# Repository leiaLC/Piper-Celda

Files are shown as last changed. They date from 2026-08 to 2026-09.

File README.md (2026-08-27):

# PiperCelda — celda de digitalización Omica

Simulación en Gazebo Harmonic + MoveIt 2 de una celda robótica que toma
laminillas de un escurridor y las coloca en microscopios Zaber Nucleus MSR.
El brazo es un **AgileX PiPER X** de 6 GDL con pinza paralela.

---

## Requisitos

- Ubuntu 24.04
- ROS 2 Jazzy
- Gazebo Harmonic (`gz sim` 8.x)

```bash
sudo apt install -y \
  ros-jazzy-gz-ros2-control ros-jazzy-ros-gz-sim ros-jazzy-ros-gz-bridge \
  ros-jazzy-moveit ros-jazzy-joint-state-broadcaster \
  ros-jazzy-joint-trajectory-controller ros-jazzy-position-controllers \
  ros-jazzy-xacro ros-jazzy-controller-manager
```

Solo para regenerar geometría (no hace falta para correr la simulación):

```bash
pip install --break-system-packages trimesh shapely rtree mapbox-earcut \
  fast-simplification coacd scipy numpy
```

---

## Arrancar

Dos terminales.

### Terminal 1 — Gazebo

```bash
cd ~/Omica/PiperCelda
source /opt/ros/jazzy/setup.bash
colcon build --symlink-install
source install/setup.bash
export __NV_PRIME_RENDER_OFFLOAD=1 __GLX_VENDOR_LIBRARY_NAME=nvidia
ros2 launch piper_celda_gazebo celda_piper.launch.py
```

Espera a que los tres controladores estén activos:

```bash
ros2 control list_controllers
# joint_state_broadcaster   ... active
# brazo_controller          ... active
# pinza_controller          ... active
```

### Terminal 2 — MoveIt + RViz

```bash
cd ~/Omica/PiperCelda
source /opt/ros/jazzy/setup.bash
source install/setup.bash
ros2 launch piper_celda_moveit moveit.launch.py
```

RViz arranca ya configurado y publica la escena de la celda a los 10 s.
Espera a ver `You can start planning now!`.

Para planificar: panel **MotionPlanning**, pestaña *Planning*, grupo `brazo`,
elige un *Goal State* o arrastra el marcador del TCP, **Plan**, **Execute**.

### Argumentos útiles

| Launch | Argumento | Por defecto | Para qué |
|---|---|---|---|
| `celda_piper` | `gui` | `true` | `false` = solo servidor |
| `celda_piper` | `pausado` | `false` | arrancar en pausa |
| `celda_piper` | `x` `y` `z` `yaw` | de `pose_brazo.yaml` | mover la base del brazo |
| `moveit` | `rviz` | `true` | `false` = solo `move_group` |
| `moveit` | `escena` | `true` | publicar la geometría de la celda |
| `moveit` | `seguir` | `true` | seguir en vivo lo que muevas en Gazebo |
| `moveit` | `retardo` | `10.0` | espera antes de publicar la escena |

---

## Estructura

```
~/Omica/PiperCelda/src/
├── piper_celda_description/     brazo: URDF, mallas, controladores
│   ├── config/pose_brazo.yaml   POSE DE LA BASE (fuente única)
│   ├── config/piper_controllers.yaml
│   ├── meshes/dae/              visual (9 mallas)
│   ├── meshes/collision/        cascos convexos
│   ├── meshes/extra/            gripper_base y J8 corregida
│   └── urdf/piper_x.urdf.xacro
├── piper_celda_gazebo/          mundo y modelos de la celda
│   ├── worlds/celda_piper.sdf
│   ├── models/{mesa,microscopio_msr,escurridor_60,laminilla}
│   └── launch/celda_piper.launch.py
└── piper_celda_moveit/          planificación
    ├── config/piper_x.srdf      grupos y matriz de colisiones
    ├── config/moveit.rviz
    ├── launch/moveit.launch.py
    └── scripts/
        ├── publicar_escena_celda.py
        └── manipular_laminilla.py
```

---

## La laminilla

MoveIt trata la laminilla como obstáculo rígido, así que rechaza cualquier
trayectoria que la roce — incluido el propio agarre. Dos mecanismos, en
momentos distintos:

```bash
# ANTES de planificar la aproximación: los dedos pueden tocarla
ros2 run piper_celda_moveit manipular_laminilla.py permitir

# AL CERRAR la pinza: pasa a ser parte del robot y viaja con él
ros2 run piper_celda_moveit manipular_laminilla.py adjuntar

# AL SOLTARLA
ros2 run piper_celda_moveit manipular_laminilla.py soltar

# Ver en qué estado está todo
ros2 run piper_celda_moveit manipular_laminilla.py estado
```

Con `--objeto laminilla_02 --link Link7` para otras laminillas o links.

---

## Cambiar la pose del brazo

**Solo** en `src/piper_celda_description/config/pose_brazo.yaml`. Ese archivo
lo leen los dos launch. Si pones la pose en cualquier otro sitio, Gazebo y
MoveIt acabarán discrepando y el fallo es silencioso: no hay error, solo
planes que no corresponden a la simulación.

---

## Mover objetos de la celda

Arrastra los modelos en la GUI de Gazebo: la escena de MoveIt se actualiza
sola en menos de un segundo (`seguir:=true`). Dos límites:

- Solo sigue **poses**. Si añades o borras un modelo, reinicia el nodo.
- Los cambios **no** se guardan. Cuando te convenza la disposición:
  *File → Save World As* sobre `src/piper_celda_gazebo/worlds/celda_piper.sdf`.

---

## Regenerar geometría

Solo si cambia el CAD de origen.

```bash
# Reexportar el microscopio desde FreeCAD (workbench Mesh Design,
# Meshes -> Create mesh from shape, desviación 0.1 mm), luego:
python3 herramientas/10_orientar_microscopio.py ~/Downloads/model.stl

# Colisiones por descomposición convexa (~16 L, sigue la forma real)
python3 herramientas/12_colision_convexa.py --piezas 48

# Alternativa por cajas (~25 L, más rápida de evaluar)
python3 herramientas/11_regenerar_colisiones.py --cajas 16
```

Ambas tienen `--revertir`.

---

## Problemas conocidos

**Los microscopios parpadean en RViz.** Los 48 cascos convexos se solapan y
compiten por los mismos píxeles. El *Scene Alpha* está a 0.75 para
disimularlo. Es cosmético.

**`No executable found` tras extraer un tar.** Los scripts necesitan permiso
de ejecución en el fuente, porque `--symlink-install` instala enlaces:

```bash
chmod +x src/piper_celda_moveit/scripts/*.py
colcon build --symlink-install --packages-select piper_celda_moveit
```

**`ParseError: not well-formed` al publicar la escena.** Algún `model.sdf`
tiene `<`, `>`, `&` o `--` dentro de un comentario. Gazebo lo tolera (usa
TinyXML2), Python no. Para localizarlo:

```bash
for f in src/piper_celda_gazebo/models/*/model.sdf; do
  python3 -c "import xml.etree.ElementTree as E,sys;E.parse(sys.argv[1])" "$f" \
    2>/dev/null && echo "OK   $f" || echo "ROTO $f"
done
```

En los comentarios de SDF, usa `===` para separar, no guiones.

**Gazebo renderiza en la Intel en vez de la NVIDIA.** Es óptimus sin
offload; de ahí el `failed to create dri2 screen`. Las variables
`__NV_PRIME_RENDER_OFFLOAD` del arranque lo corrigen.

---

## Notas sobre el modelo del brazo

El `piper_x_description` original de AgileX (repo `piper_isaac_sim`) tiene
tres defectos que este paquete corrige:

1. **Falta el `gripper_base`.** El URDF monta los dedos directamente sobre
   `Link6`, dejando 33 mm de aire. La malla se tomó de la descripción
   canónica de AgileX, girada 90° en Z para la convención de la variante X.
2. **`Link7` con `mass=0`** e inercia nula. Gazebo lo rechaza. Se le asignó
   la masa e inercia de `Link8`, que es su espejo.
3. **`J8.dae` con dos triángulos parásitos**, uno a 240 mm del origen.

Además, las colisiones originales usaban las mismas mallas que el visual
(`J2.dae` son 100 980 triángulos). Se sustituyeron por cascos convexos:
240 765 → 7 140 triángulos. Los dedos conservan malla original, porque un
casco convexo taparía la abertura de la pinza.

**Datos verificados por cinemática directa:** alcance horizontal máximo
838 mm, y 833 mm a la altura de la base. Home (todos los joints en 0) deja
el TCP en (0.267, 0, 0.233) m respecto de `base_link` — pero esa pose está
sobre dos topes articulares (`joint2` tiene límite inferior 0, `joint3`
superior 0), así que el SRDF define `plegado` y `listo` para evitarla.

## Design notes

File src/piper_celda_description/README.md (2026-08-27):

# piper_celda_description

Descripción del brazo **AgileX PiPER X** adaptada a **Gazebo Harmonic + ROS 2 Jazzy**
para la celda de digitalización de Omica.

Origen: `github.com/agilexrobotics/piper_isaac_sim`, paquete `piper_x_description`.

## Cambios respecto al URDF original

| # | Problema en el original | Solución aquí |
|---|---|---|
| 1 | `Link7` (dedo) declarado con `mass="0.0"` y tensor de inercia todo en cero. Gazebo lo rechaza o lo vuelve inestable. | Se le asigna la masa (0.026482 kg) y la inercia de `Link8`, que es su espejo. |
| 2 | Colisiones usando las mismas mallas DAE que el visual: `J2.dae` son 100 980 triángulos. Inviable en simulación. | Cascos convexos en STL para `base_link`–`Link6`. De 240 765 a 7 140 triángulos de colisión. Los dedos `Link7`/`Link8` conservan malla original (1 838 tri) porque un casco convexo taparía la abertura de la pinza. |
| 3 | `joint7` y `joint8` como dos prismáticas independientes. La pinza real tiene un solo actuador. | `joint8` declarado `<mimic>` de `joint7` con multiplicador −1. Solo se comanda `joint7`. |
| 4 | Sin `ros2_control`, sin plugin de simulador, sin propiedades de contacto. | Bloque `ros2_control` con `gz_ros2_control/GazeboSimSystem` + plugin `gz_ros2_control-system`. Fricción alta (μ=1.6) en los dedos. |
| 5 | Sin frame de herramienta. | Link `tcp` a 170 mm de `Link6`, entre los dedos. Es el frame que planificará MoveIt. |
| 6 | Recorrido de pinza ±0.05 m (100 mm de apertura), que no corresponde al hardware. | Limitado a 0.035 m. Ajustar si mides otra cosa en el brazo real. |

## Cinemática verificada

- 6 revolutas (`joint1`–`joint6`) + 1 GDL de pinza (`joint7`, con `joint8` espejo).
- Home (todos los joints en 0): TCP en (0.267, 0, 0.233) m respecto a `base_link`.
- Alcance horizontal máximo: **838 mm**, y **833 mm** a la altura de la base.

## Uso

```bash
# Ver el URDF resultante
xacro urdf/piper_x.urdf.xacro usar_gazebo:=false > /tmp/piper.urdf
check_urdf /tmp/piper.urdf

# Sin anclaje al mundo (brazo libre)
xacro urdf/piper_x.urdf.xacro fijar_a_mundo:=false
```

### Argumentos del xacro

| Argumento | Default | Para qué |
|---|---|---|
| `prefix` | `""` | Prefijo de nombres, por si algún día hay dos brazos. |
| `fijar_a_mundo` | `true` | Añade link `world` + joint fijo a `base_link`. Necesario para que el brazo no se vuelque sobre la mesa. |
| `usar_gazebo` | `true` | Incluye `ros2_control` y el plugin. Ponlo en `false` para RViz puro o para MoveIt Setup Assistant. |
| `controllers_file` | `config/piper_controllers.yaml` | YAML que carga el plugin. |

## Controladores

- `joint_state_broadcaster`
- `brazo_controller` — `JointTrajectoryController` sobre `joint1`–`joint6`
- `pinza_controller` — `JointTrajectoryController` sobre `joint7`

## Pendientes conocidos

- Los cascos convexos de `Link2` y `Link3` engordan ligeramente los links respecto a la
  geometría real. Para el chequeo fino de holguras contra los microscopios conviene
  contrastar con el visual.
- La pinza es la de serie. Según la decisión de rediseño de mordazas (Delrin/PEEK con
  nido en V), habrá que sustituir la geometría de `Link7`/`Link8`.

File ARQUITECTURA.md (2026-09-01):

# Cómo funciona la celda, por dentro

Documento para entender qué hace cada pieza y poder modificarla. Complementa
al README, que es la guía de uso.

---

## 1. Las tres capas y por qué están separadas

Corren tres cosas distintas que se hablan por ROS 2:

```
   GAZEBO                    ros2_control                MOVEIT
   física, contactos    <->  puente al robot      <->    planificación
   render                    controladores               colisiones
```

**Gazebo** simula física: gravedad, contactos, inercias. No sabe planificar.
Solo obedece posiciones articulares y calcula qué pasa.

**ros2_control** es el puente. Dentro de Gazebo corre el plugin
`gz_ros2_control`, que expone cada articulación como una *interfaz*: una de
comando (dónde quiero que esté) y varias de estado (dónde está, a qué
velocidad, con qué esfuerzo). Encima viven los controladores, que traducen
trayectorias en comandos.

**MoveIt** planifica. Nunca toca Gazebo directamente: calcula una trayectoria
y se la entrega a un controlador. Su modelo del mundo es la *escena de
planificación*, que alguien tiene que rellenar — ese alguien es nuestro script.

La separación importa porque **cada capa puede estar bien y el conjunto mal**.
La mitad de los problemas de esta sesión fueron eso: MoveIt planificando con
el brazo en una pose y Gazebo simulándolo en otra, o dos simulaciones a la vez
y el comando yendo a la que no mirabas.

---

## 2. El recorrido de un movimiento

Cuando pides "lleva el TCP a este punto":

1. **RViz o un script** manda un *goal* a la acción `/move_action`.
2. **`move_group`** recibe la petición. Aplica adaptadores previos (¿el estado
   inicial es válido? ¿está dentro de límites?) y llama a **OMPL**.
3. **OMPL** busca un camino en el espacio de configuraciones muestreando al
   azar. Cada muestra se comprueba contra la escena de planificación con FCL.
   Si no encuentra ninguna configuración válida que alcance el objetivo, sale
   el `Unable to sample any valid states for goal tree`.
4. Encontrado el camino, un adaptador posterior le pone tiempos
   (`AddTimeOptimalParameterization`) respetando `joint_limits.yaml`.
5. `move_group` mira `moveit_controllers.yaml`, ve qué controlador maneja esas
   articulaciones, y le manda la trayectoria por `FollowJointTrajectory`.
6. **`brazo_controller`** interpola la trayectoria y escribe posiciones en las
   interfaces de comando, ciclo a ciclo.
7. **`gz_ros2_control`** aplica esas posiciones a las articulaciones de Gazebo.
8. Gazebo integra la física y publica el estado de vuelta, que sube por la
   misma cadena hasta `/joint_states`.

Si algo falla, el paso donde falla determina el síntoma. Vale la pena
memorizar tres:

- *"Unable to sample any valid states"* → paso 3. El objetivo es inalcanzable
  o está en colisión.
- *"followed 0% of requested trajectory"* → cálculo cartesiano. El punto de
  partida ya está en colisión, o el camino recto es imposible.
- *"Aborted due to path tolerance violation"* → paso 6. El controlador manda
  pero la articulación no llega.

---

## 3. Las tres piezas del brazo

### `piper_x.urdf.xacro` — la geometría y la cinemática

Un xacro es un URDF con plantillas. Describe **links** (piezas rígidas, con
masa, inercia, malla visual y malla de colisión) y **joints** (cómo se conecta
cada link con el anterior y en qué eje gira o desliza).

La cadena es `world → base_link → Link1 … Link6 → gripper_base → Link7/Link8`,
más un link `tcp` de cortesía.

Tres cosas que conviene entender:

**El link `world` y `anclaje_mundo`.** Sin ellos el brazo sería un objeto
libre. La junta fija `world → base_link` es la que lo planta sobre la mesa, y
su origen sale de `pose_brazo.yaml`. Esta junta es la razón de que Gazebo y
MoveIt coincidan: los dos leen el mismo archivo.

**Colisión distinta del visual.** El visual usa las mallas `.dae` originales
(`J2.dae` son 100 980 triángulos). La colisión usa cascos convexos en STL, con
7 140 triángulos en total. Comprobar colisiones contra 240 000 triángulos en
cada muestra de OMPL sería inviable, y la precisión no aporta nada a esta
escala. Los dedos son la excepción: conservan malla original, porque un casco
convexo taparía la abertura de la pinza.

**`gripper_base` no viene del fabricante.** El URDF de AgileX para la variante
X monta los dedos directamente sobre `Link6`, dejando 33 mm de aire. La malla
se tomó de su descripción canónica y se giró 90° en Z.

### `piper_x.gazebo.xacro` — la interfaz de control

Aquí vive el bloque `<ros2_control>`, que declara qué articulaciones se pueden
comandar y con qué interfaces. Y el `<plugin>` que mete `gz_ros2_control`
dentro de Gazebo, apuntándole al YAML de controladores.

Aquí también están las propiedades de contacto: fricción alta (μ=1.6) en los
dedos para que la laminilla no resbale, baja en el resto.

`joint8` se comanda explícitamente, en espejo de `joint7`. La pinza real tiene
un solo actuador y lo natural sería un `<mimic>`, pero en Jazzy eso dio
problemas y la solución fue mandar los dos dedos desde el controlador.

### `piper_controllers.yaml` — los controladores

Tres: `joint_state_broadcaster` (publica `/joint_states`), `brazo_controller`
(joints 1–6) y `pinza_controller` (joints 7 y 8).

Las **tolerancias** son el parámetro con más consecuencias. Son holgadas a
propósito en la pinza: al cerrar sobre la laminilla el dedo *tiene* que
quedarse corto respecto al comando, porque hay vidrio en medio. Con tolerancia
estricta, cada agarre exitoso se reportaría como fallo. El precio es que si la
pinza se atasca de verdad, el controlador no avisa.

---

## 4. Las tres piezas de MoveIt

### `piper_x.srdf` — lo que el URDF no dice

El URDF describe la máquina. El SRDF describe **cómo usarla**:

- **Grupos**: `brazo` es la cadena de `base_link` a `tcp`; `pinza` son los dos
  dedos. Planificas sobre un grupo, no sobre el robot entero.
- **Poses con nombre**: `plegado`, `listo`, `abierta`, `cerrada`. La pose de
  todo-ceros no sirve como *home* porque `joint2` tiene límite inferior 0 y
  `joint3` superior 0: con ceros el brazo queda sobre dos topes y el
  planificador rechaza ese estado inicial.
- **La matriz de colisiones**: 26 pares desactivados. Sin ella, MoveIt
  comprobaría cada par de links en cada muestra, y además rechazaría estados
  válidos — dos links contiguos siempre se tocan en la junta.

Esa matriz no está escrita a ojo. Se calculó muestreando 3 000 configuraciones
aleatorias y midiendo qué pares llegaban a tocarse: 11 adyacentes, 14 que no
se tocaron nunca, y `Link7`/`Link8`, que hay que desactivar o MoveIt se niega
a cerrar la pinza.

### `kinematics.yaml`, `joint_limits.yaml`, `ompl_planning.yaml`

El primero elige el solucionador de cinemática inversa (KDL). El segundo pone
techo a velocidades y aceleraciones — deliberadamente por debajo de lo que
declara el URDF, porque en simulación de layout interesa poder seguir el
movimiento con la vista. El tercero configura OMPL: `RRTConnect` por defecto,
que crece dos árboles desde inicio y meta hasta que se encuentran.

### `moveit_controllers.yaml`

Le dice a MoveIt qué controlador maneja qué articulaciones. Si los nombres no
coinciden con `piper_controllers.yaml`, MoveIt planifica pero *Execute* no
hace nada.

---

## 5. `publicar_escena_celda.py` — meter el mundo en MoveIt

MoveIt no sabe nada de Gazebo. Su mundo es la escena de planificación, y
arranca vacía.

Este nodo lee **el mismo `celda_piper.sdf` que carga Gazebo**, resuelve cada
`model://` contra la misma carpeta `models/`, y publica la geometría como
objetos de colisión. Esa decisión es deliberada: no hay geometría escrita a
mano en ningún sitio, así que la escena y la simulación no pueden divergir.

Lo que hace, en orden:

1. **Parsea el SDF** con `ElementTree`. Aquí apareció un problema curioso:
   Gazebo usa TinyXML2, que tolera `<`, `>` y `--` dentro de comentarios;
   Python sigue el estándar y los rechaza. Mismo archivo, dos lectores con
   criterios distintos.
2. **Compone poses en tres niveles**: la del `<include>` en el mundo, la del
   `<model>` dentro de su archivo, y la de cada `<collision>` dentro del link.
   Se multiplican matrices de rotación y se suman traslaciones.
3. **Lee las mallas**. Lleva un lector de STL binario en Python puro para no
   depender de `trimesh` en tiempo de ejecución.
4. **Publica** por el servicio `apply_planning_scene`.

Con `seguir:=true` no termina: se suscribe a las poses que Gazebo publica
—puenteadas a `/poses_gazebo`— y reenvía cualquier modelo que muevas en la
GUI. Guarda la geometría **en el marco de cada modelo** y solo recompone la
pose cuando cambia; releer las 48 mallas del microscopio a 2 Hz sería
inviable. Refresca cada 0.5 s y solo si el modelo se movió más de 1 mm.

Solo sigue poses. Si añades o borras un modelo en Gazebo, hay que reiniciarlo.

---

## 6. `agarrar_laminilla.py` — la secuencia

### La geometría, primero

La laminilla mide 76 × 26 × 1 mm y está de canto en el escurridor. Su espesor
va en X (dirección de las ranuras), su ancho en Y, su alto en Z. Centro en
z = 0.798, borde superior en 0.836.

El punto de agarre está 20 mm por debajo del borde: **z = 0.816**. El TCP está
en la punta de los dedos, así que poner el TCP ahí hace que la zona de contacto
de las mordazas cubra exactamente esos 20 mm superiores.

**La orientación** determina dónde apoya la mordaza:

| | cierra sobre | apoyo de la mordaza |
|---|---|---|
| `cantos` | 26 mm de ancho | 1 mm de canto |
| `caras` | 1 mm de espesor | 26 mm de cara |

En las dos, el eje Z del TCP mira hacia −Z del mundo. Lo que cambia es el eje
X, que es por donde cierran los dedos. Están precalculadas como cuaterniones
en `ORIENTACIONES`.

La abertura se deduce de ahí: cada dedo se separa `joint7` del centro, así que
la abertura total es el doble. Por eso no puede haber un valor único por
defecto — 26 mm y 1 mm piden aperturas muy distintas.

### Los siete pasos

**1. Abrir la pinza.** Antes de acercarse, no después. Con una espera de un
segundo tras confirmar el movimiento: la acción reporta éxito cuando el
controlador alcanza el objetivo, pero los dedos siguen asentándose, y arrancar
el descenso con la pinza todavía abriendo empuja la laminilla.

**2. Permitir el contacto.** Se marca en la matriz de colisiones que los links
de la pinza pueden tocar la laminilla. Sin esto no hay plan posible: agarrar
*es* tocar. También se permite el contacto laminilla–escurridor, y eso no es
una concesión: la laminilla **arranca metida en la ranura**, así que en cuanto
se adjunta al robot esa interpenetración cuenta como colisión robot–mundo y
ninguna trayectoria de salida sería válida.

**3. Ir al preagarre**, 100 mm por encima. Este tramo sí es un plan articular
normal: no importa por dónde pase mientras evite obstáculos.

**4. Descenso, en dos tramos.** Libre de colisiones hasta 35 mm del agarre; los
últimos 35 mm sin comprobar colisiones. Esos milímetros son contacto por
definición y exigir ausencia de colisión ahí es contradictorio — el
planificador se planta justo al llegar al borde superior de la laminilla. El
tramo liberado es corto, estrictamente vertical, y parte de un punto que sí se
verificó. Lo único que puede tocar es la laminilla que vas a agarrar.

Los dos tramos son **cartesianos**, no articulares. Un plan articular solo
garantiza que inicio y fin están libres; por el camino el TCP puede describir
un arco, y con las ranuras vecinas a 8 mm un arco las barre.

**5. Cerrar la pinza.**

**6. Adjuntar.** La laminilla pasa del mundo a la lista de cuerpos adjuntos del
robot. Desde ahí MoveIt la mueve con el brazo y comprueba **sus** colisiones
contra la celda — importante, porque 76 mm de vidrio sobresaliendo de la pinza
cambian el volumen que hay que hacer pasar entre los microscopios.

Dos trampas aquí, ambas encontradas a golpes:

- MoveIt calcula la posición del objeto *relativa al link* usando el estado del
  robot en ese instante. Si se adjunta con el brazo en casa, la laminilla queda
  enganchada con el desfase equivocado. Por eso el script declara
  explícitamente en qué configuración está el robot.
- No hay que mandar un `REMOVE` del objeto en el mundo. Adjuntar por id ya lo
  saca. Si se manda, MoveIt procesa el borrado primero y luego no encuentra qué
  adjuntar: queda un cuerpo vacío en la pinza.

**7. Retirada**, también en dos tramos, en espejo del descenso.

### Modo seco contra ejecución real

Con `--solo-planificar` el robot no se mueve, así que cada tramo debe partir
del final planificado del anterior — si no, el segundo tramo cartesiano se
calcula desde donde está el brazo de verdad y devuelve 0 %.

En ejecución real ocurre lo contrario: cada tramo parte del estado **medido**.
Si el controlador se queda corto por unos milímetros, el siguiente tramo lo
tiene en cuenta en vez de arrastrar el error.

El modo seco deja la laminilla adjunta en la escena. Para devolverla a su
sitio, vuelve a correr `publicar_escena_celda.py`.

---

## 7. Qué tocar para cambiar cada cosa

| Quiero… | Toco |
|---|---|
| mover la base del brazo | `pose_brazo.yaml`, y **solo** ahí |
| cambiar dónde agarra | `--bajo-borde`, o el cálculo de `z_agarre` |
| agarre por cantos | `--orientacion cantos` |
| más o menos apriete | `--apriete`, `--holgura` |
| que vaya más lento | `--velocidad 0.05` |
| brazo más rápido en general | `joint_limits.yaml` |
| que deje de chocar con algo | la matriz del `piper_x.srdf` |
| añadir un obstáculo | el `celda_piper.sdf`; la escena lo recoge sola |
| otro planificador | `ompl_planning.yaml` |
| colisiones del microscopio | `herramientas/12_colision_convexa.py` |

---

## 8. Lo que esta simulación no te dice

**El agarre físico.** MoveIt lleva la laminilla adjunta cinemáticamente,
pegada a `Link7`, pase lo que pase. Gazebo simula contacto de verdad. Los dos
pueden discrepar, y de hecho discrepan: una laminilla de 5 g y 1 mm sujeta por
una pinza controlada en posición tiende a salir disparada por el error de
penetración. Que RViz muestre el agarre perfecto no significa que el agarre
real vaya a funcionar.

**Las mordazas.** El agarre por caras que usa el script por defecto **no cabe
con el escurridor lleno**: las ranuras están a 8 mm y cada mordaza tendría que
medir menos de 3 mm. Sirve para validar cinemática y secuencia; para operación
real dependen del rediseño de mordazas.

**La vibración.** Nada en esta simulación modela lo que le pasa a la óptica de
un microscopio cuando un brazo se mueve a su lado.

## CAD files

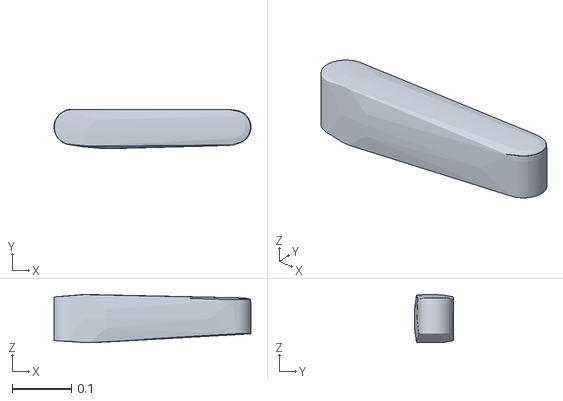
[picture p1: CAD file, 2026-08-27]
src/piper_celda_description/meshes/collision/J3_col.stl
0.331 x 0.0664 x 0.0807

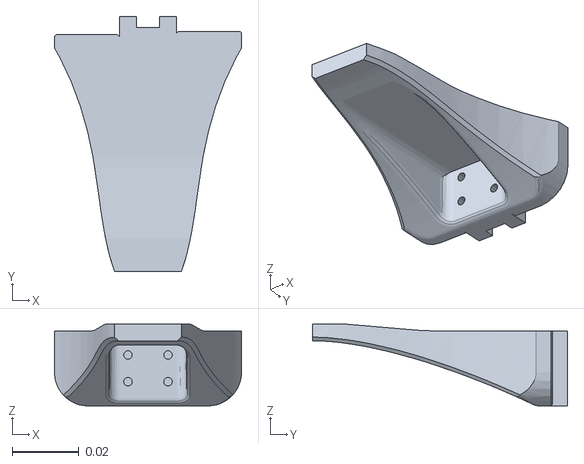
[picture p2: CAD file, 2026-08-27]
src/piper_celda_description/meshes/extra/J8_limpio.stl
0.056 x 0.0765 x 0.0245

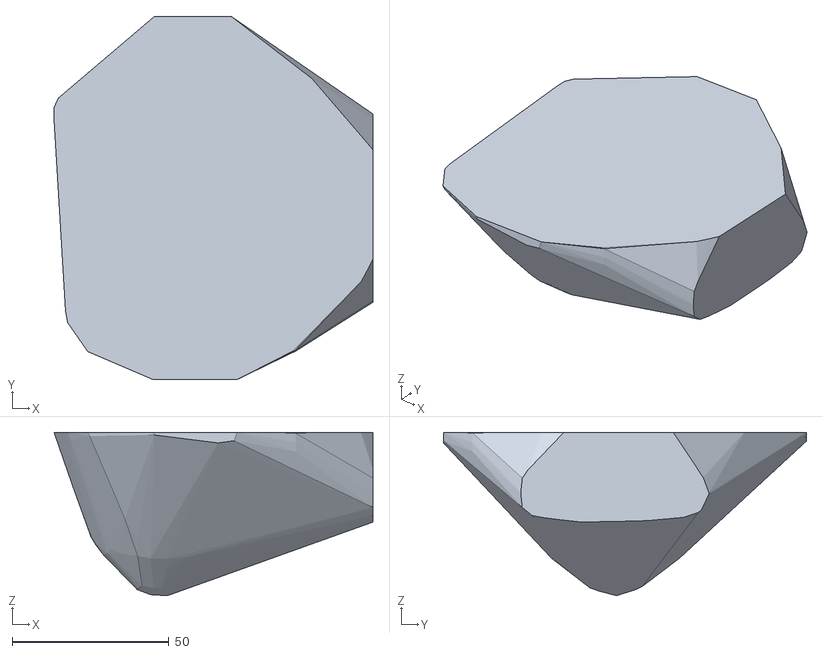
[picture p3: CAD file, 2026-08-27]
src/piper_celda_gazebo/models/microscopio_msr/meshes/collision/col_43.stl
101.8 x 115.9 x 52.1

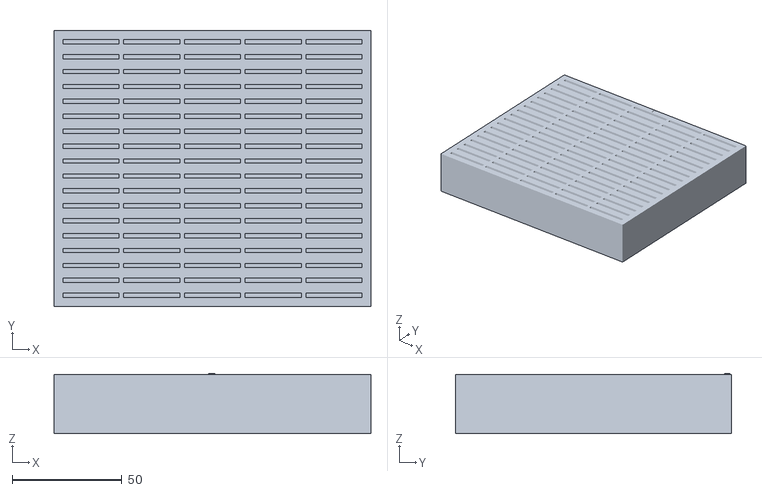
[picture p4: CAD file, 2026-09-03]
src/piper_celda_gazebo/models/rack_laminillas/meshes/rack_laminillas.stl
144.5 x 125.6 x 27.5

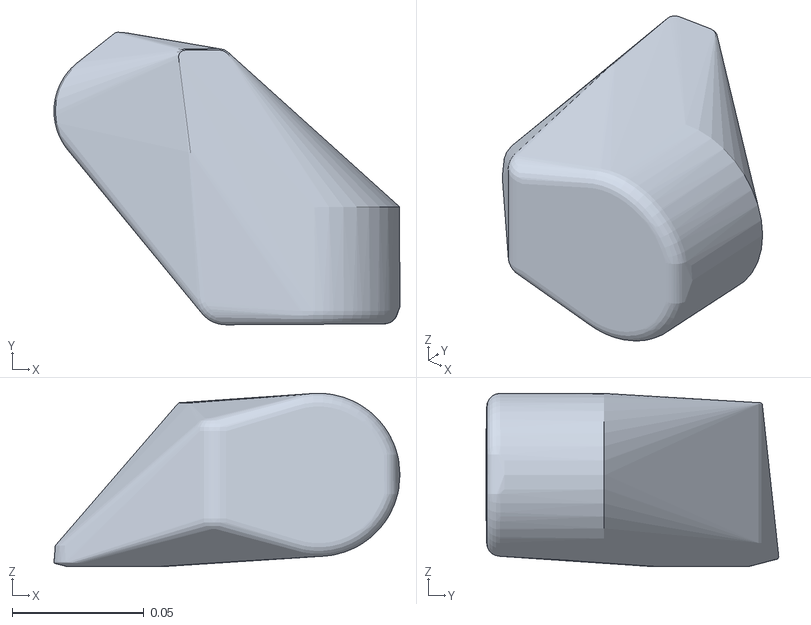
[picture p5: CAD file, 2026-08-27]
src/piper_celda_description/meshes/collision/J4_col.stl
0.132 x 0.111 x 0.0659

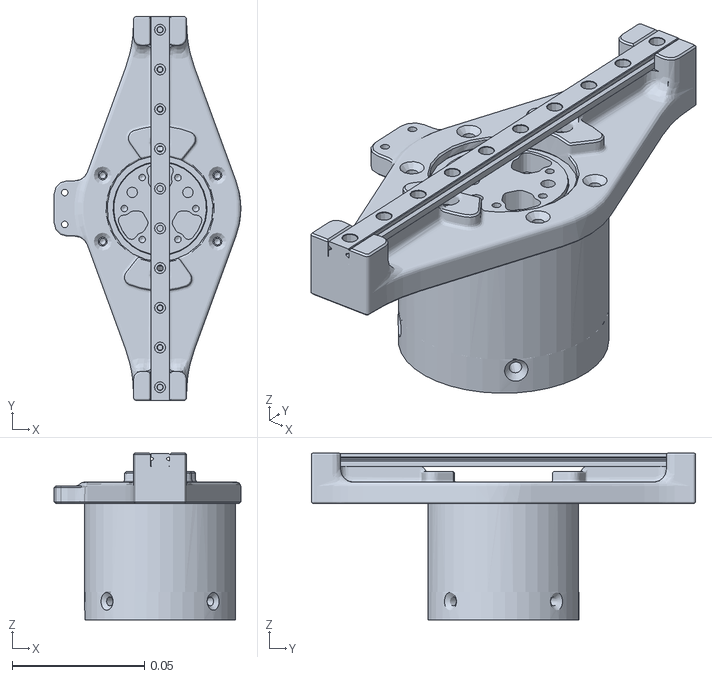
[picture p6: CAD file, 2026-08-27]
src/piper_celda_description/meshes/extra/gripper_base.stl
0.0705 x 0.145 x 0.063

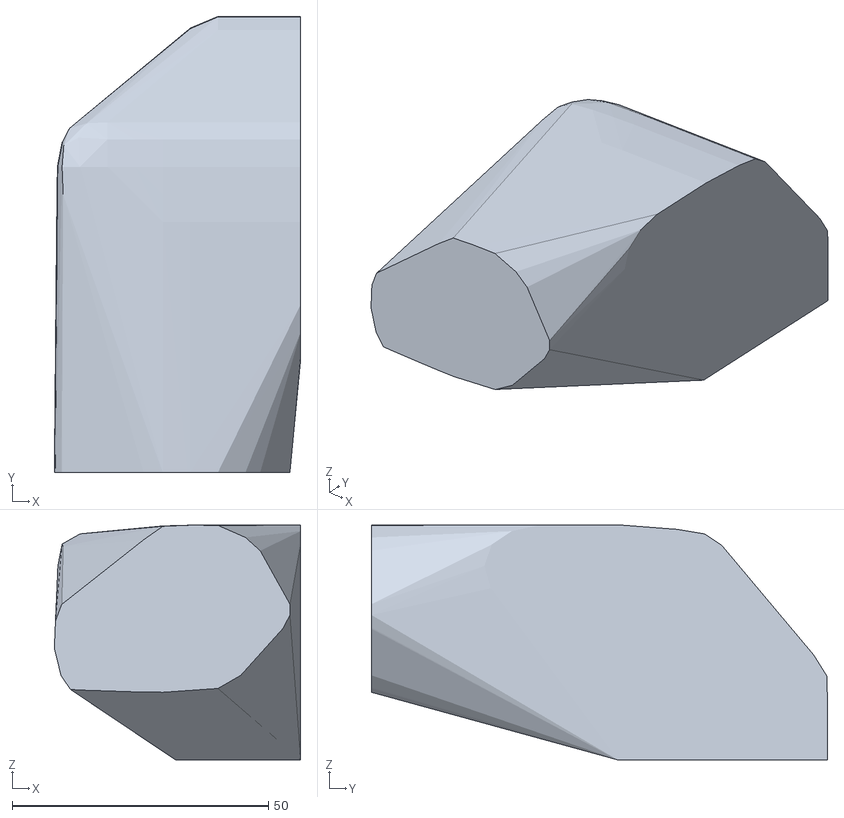
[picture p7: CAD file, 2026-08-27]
src/piper_celda_gazebo/models/microscopio_msr/meshes/collision/col_38.stl
48.1 x 89.0 x 45.8

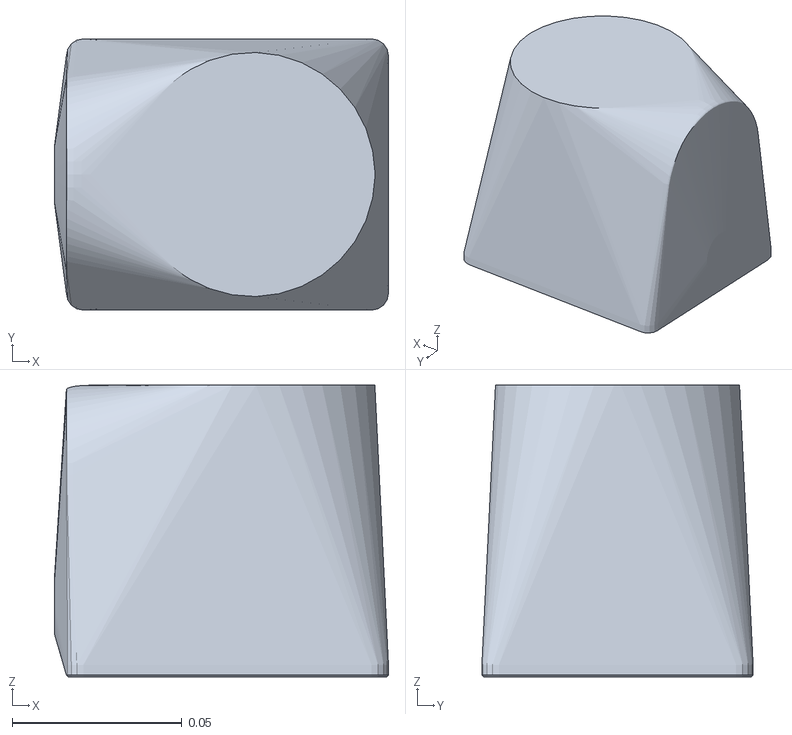
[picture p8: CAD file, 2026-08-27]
src/piper_celda_description/meshes/collision/base_Link_col.stl
0.0985 x 0.08 x 0.086

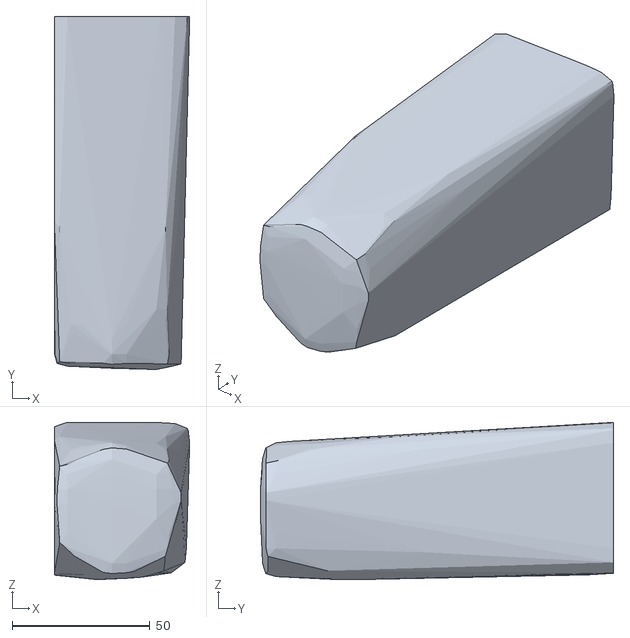
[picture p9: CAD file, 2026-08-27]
src/piper_celda_gazebo/models/microscopio_msr/meshes/collision/col_07.stl
49.1 x 127.9 x 57.0

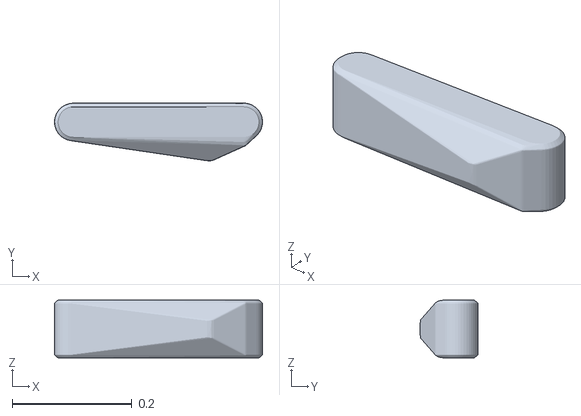
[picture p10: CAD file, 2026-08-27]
src/piper_celda_description/meshes/collision/J2_col.stl
0.348 x 0.0965 x 0.097

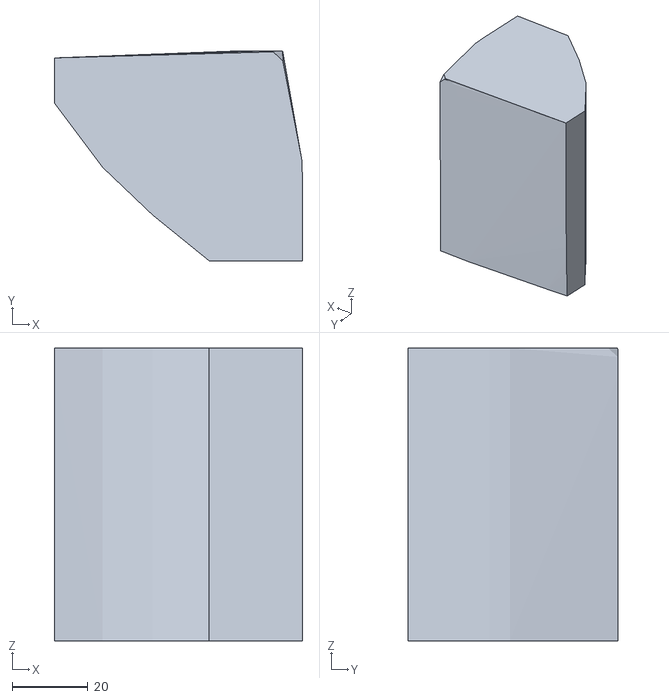
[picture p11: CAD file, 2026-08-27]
src/piper_celda_gazebo/models/microscopio_msr/meshes/collision/col_15.stl
65.7 x 55.5 x 77.6

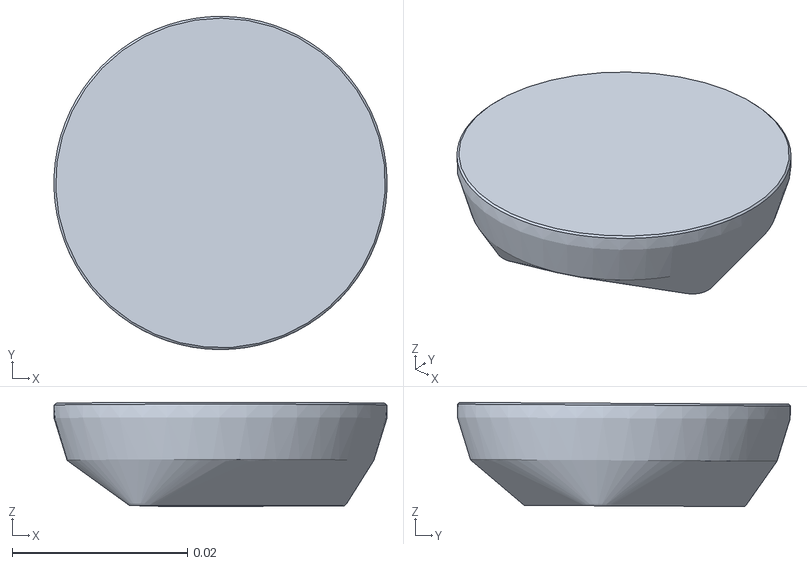
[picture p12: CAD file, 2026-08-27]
src/piper_celda_description/meshes/collision/J6_col.stl
0.038 x 0.038 x 0.0119

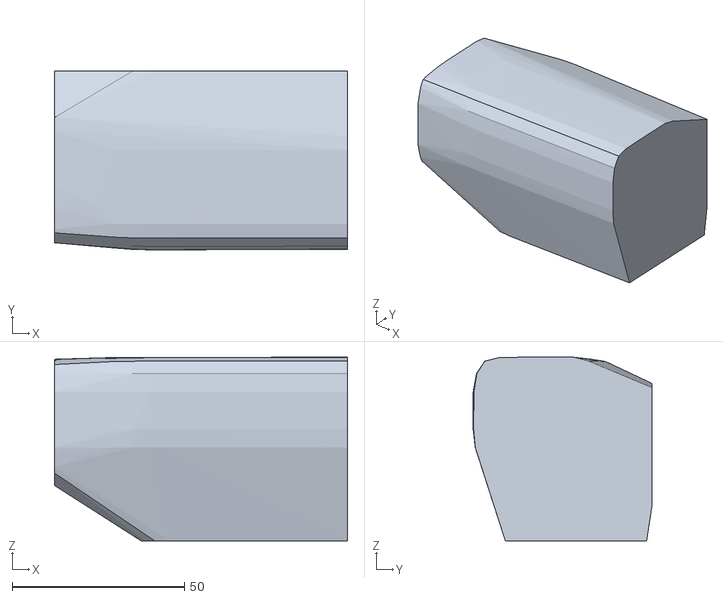
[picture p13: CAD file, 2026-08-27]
src/piper_celda_gazebo/models/microscopio_msr/meshes/collision/col_33.stl
85.2 x 52.0 x 53.4

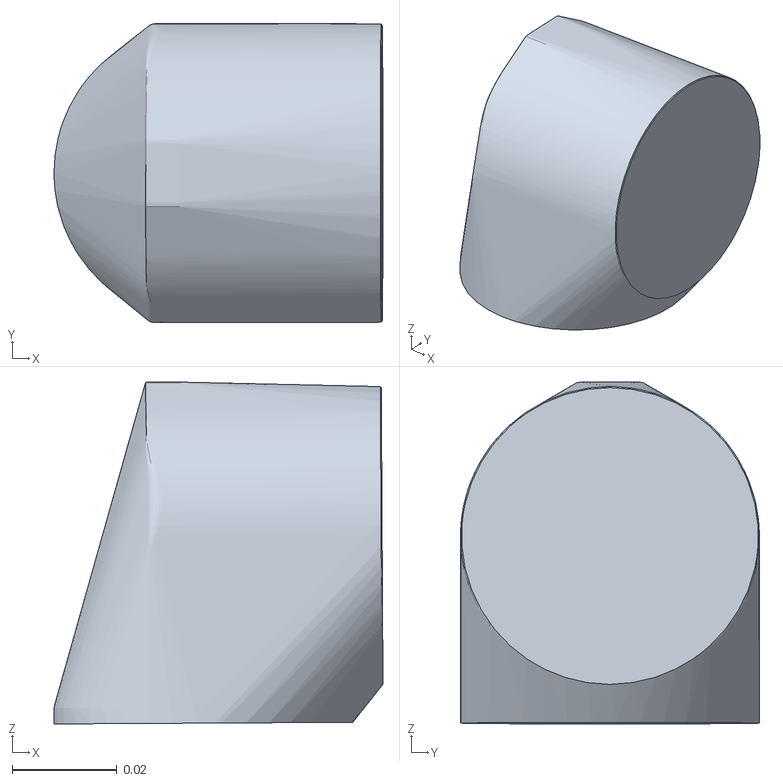
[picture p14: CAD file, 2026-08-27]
src/piper_celda_description/meshes/collision/J5_col.stl
0.0628 x 0.057 x 0.0652

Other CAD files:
src/piper_celda_gazebo/models/microscopio_msr/meshes/collision/col_03.stl
src/piper_celda_description/meshes/collision/gripper_base_col.stl
src/piper_celda_gazebo/models/microscopio_msr/meshes/collision/col_10.stl
src/piper_celda_description/meshes/collision/J1_col.stl
src/piper_celda_gazebo/models/microscopio_msr/meshes/collision/col_00.stl
src/piper_celda_gazebo/models/microscopio_msr/meshes/collision/col_01.stl
src/piper_celda_gazebo/models/microscopio_msr/meshes/collision/col_02.stl
src/piper_celda_gazebo/models/microscopio_msr/meshes/collision/col_04.stl
src/piper_celda_gazebo/models/microscopio_msr/meshes/collision/col_05.stl
src/piper_celda_gazebo/models/microscopio_msr/meshes/collision/col_06.stl
src/piper_celda_gazebo/models/microscopio_msr/meshes/collision/col_08.stl
src/piper_celda_gazebo/models/microscopio_msr/meshes/collision/col_09.stl
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

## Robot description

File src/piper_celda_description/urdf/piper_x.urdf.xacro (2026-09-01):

<?xml version="1.0"?>
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
<robot xmlns:xacro="http://www.ros.org/wiki/xacro" name="piper_x">

  <xacro:arg name="prefix" default=""/>
  <xacro:arg name="fijar_a_mundo" default="true"/>

  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
  <xacro:arg name="base_x" default="0.0"/>
  <xacro:arg name="base_y" default="0.14"/>
  <xacro:arg name="base_z" default="0.754"/>
  <xacro:arg name="base_yaw" default="1.5708"/>
  <xacro:arg name="usar_gazebo" default="true"/>
  <xacro:arg name="controllers_file" default="$(find piper_celda_description)/config/piper_controllers.yaml"/>

  <xacro:property name="P" value="$(arg prefix)"/>
  <xacro:property name="mesh" value="package://piper_celda_description/meshes"/>

  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
  <xacro:macro name="piper_link" params="name visual_mesh col_mesh mass ixx ixy ixz iyy iyz izz cx cy cz material:=piper_gris">
    <link name="${P}${name}">
      <inertial>
        <origin xyz="${cx} ${cy} ${cz}" rpy="0 0 0"/>
        <mass value="${mass}"/>
        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
      </inertial>
      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
    </link>
  </xacro:macro>

  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
  <xacro:piper_link name="base_link" visual_mesh="base_Link.dae" col_mesh="collision/base_Link_col.stl" mass="0.47421" cx="-0.0085443" cy="4.8839E-05" cz="0.044762" ixx="0.00044509" ixy="5.5896E-07" ixz="1.9736E-05" iyy="0.00049109" iyz="7.1578E-07" izz="0.00055319"/>

  <xacro:piper_link name="Link1" visual_mesh="J1.dae" col_mesh="collision/J1_col.stl" mass="0.16975" cx="0.0011378" cy="-0.0021698" cz="-0.014112" ixx="6.466E-05" ixy="7.2374E-07" ixz="5.1556E-08" iyy="8.8951E-05" iyz="1.0827E-07" izz="8.3142E-05"/>

  <xacro:piper_link name="Link2" visual_mesh="J2.dae" col_mesh="collision/J2_col.stl" mass="0.37783" cx="0.21036" cy="-0.01651" cz="0.0015283" ixx="0.00022199" ixy="3.2631E-05" ixz="-6.2643E-06" iyy="0.0019854" iyz="-3.0109E-06" izz="0.0020664"/>

  <xacro:piper_link name="Link3" visual_mesh="J3.dae" col_mesh="collision/J3_col.stl" mass="0.27675" cx="0.13372" cy="0.0056503" cz="-0.0017736" ixx="6.5229E-05" ixy="-1.7096E-05" ixz="1.6598E-06" iyy="0.00069125" iyz="4.6595E-07" izz="0.00071096"/>

  <xacro:piper_link name="Link4" visual_mesh="J4.dae" col_mesh="collision/J4_col.stl" mass="0.24897" cx="-9.8138E-05" cy="0.0091448" cz="-0.0074148" ixx="0.00010825" ixy="-1.1332E-07" ixz="-1.6006E-07" iyy="9.5266E-05" iyz="1.0192E-05" izz="7.4372E-05"/>

  <xacro:piper_link name="Link5" visual_mesh="J5.dae" col_mesh="collision/J5_col.stl" mass="0.13733" cx="-2.6114E-05" cy="0.0075049" cz="-0.0032612" ixx="4.4535E-05" ixy="-1.884E-08" ixz="-6.2461E-09" iyy="2.8107E-05" iyz="3.0961E-06" izz="4.1969E-05"/>

  <xacro:piper_link name="Link6" visual_mesh="J6.dae" col_mesh="collision/J6_col.stl" mass="0.013863" cx="-0.00012671" cy="0.00012415" cz="-0.021146" ixx="4.9179E-06" ixy="-1.7178E-09" ixz="-4.0674E-09" iyy="4.899E-06" iyz="3.874E-09" izz="6.0181E-06"/>

  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
  <link name="${P}gripper_base">
    <inertial>
      <origin xyz="-0.0000805 -0.000184 0.032144" rpy="0 0 0"/>
      <mass value="0.45"/>
      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
    </inertial>
    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
  </link>

  <joint name="${P}joint_gripper_base" type="fixed">
    <origin xyz="0 0 0" rpy="0 0 0"/>
    <parent link="${P}Link6"/><child link="${P}gripper_base"/>
  </joint>

  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
  <link name="${P}Link7">
    <inertial>
      <origin xyz="0.00027782 -0.046767 -0.0092103" rpy="0 0 0"/>
      <mass value="0.026482"/>
      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
    </inertial>
    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
  </link>

  <link name="${P}Link8">
    <inertial>
      <origin xyz="0.00027782 0.046767 -0.0092103" rpy="0 0 0"/>
      <mass value="0.026482"/>
      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
    </inertial>
    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
  </link>

  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
  <link name="${P}tcp"/>

  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
  <joint name="${P}joint1" type="revolute">
    <origin xyz="0 0 0.123" rpy="0 0 0"/>
    <parent link="${P}base_link"/><child link="${P}Link1"/>
    <axis xyz="0 0 1"/>
    <limit lower="-2.618" upper="2.618" effort="100" velocity="3.0"/>
    <dynamics damping="0.5" friction="0.1"/>
  </joint>

  <joint name="${P}joint2" type="revolute">
    <origin xyz="0 0 0" rpy="1.5708 -0.13586 3.1416"/>
    <parent link="${P}Link1"/><child link="${P}Link2"/>
    <axis xyz="0 0 1"/>
    <limit lower="0" upper="3.14" effort="100" velocity="3.0"/>
    <dynamics damping="0.5" friction="0.1"/>
  </joint>

  <joint name="${P}joint3" type="revolute">
    <origin xyz="0.28503 0 0" rpy="0 0 2.8377"/>
    <parent link="${P}Link2"/><child link="${P}Link3"/>
    <axis xyz="0 0 1"/>
    <limit lower="-2.9671" upper="0" effort="100" velocity="3.0"/>
    <dynamics damping="0.5" friction="0.1"/>
  </joint>

  <joint name="${P}joint4" type="revolute">
    <origin xyz="0.27264 0 0" rpy="0 0 0.075129"/>
    <parent link="${P}Link3"/><child link="${P}Link4"/>
    <axis xyz="0 0 1"/>
    <limit lower="-1.57" upper="1.57" effort="100" velocity="3.0"/>
    <dynamics damping="0.3" friction="0.1"/>
  </joint>

  <joint name="${P}joint5" type="revolute">
    <origin xyz="0.076857 0.00062395 0" rpy="-1.5708 0 0"/>
    <parent link="${P}Link4"/><child link="${P}Link5"/>
    <axis xyz="0 0 1"/>
    <limit lower="-1.57" upper="1.57" effort="100" velocity="3.0"/>
    <dynamics damping="0.3" friction="0.1"/>
  </joint>

  <joint name="${P}joint6" type="revolute">
    <origin xyz="0.035 0 0" rpy="1.5708 0 1.5708"/>
    <parent link="${P}Link5"/><child link="${P}Link6"/>
    <axis xyz="0 0 1"/>
    <limit lower="-3.14" upper="3.14" effort="100" velocity="3.0"/>
    <dynamics damping="0.3" friction="0.1"/>
  </joint>

  <joint name="${P}joint7" type="prismatic">
    <origin xyz="0 0 0.13503" rpy="1.5708 0 1.5708"/>
    <parent link="${P}Link6"/><child link="${P}Link7"/>
    <axis xyz="0 0 -1"/>
    <limit lower="0" upper="0.035" effort="60" velocity="0.5"/>
    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
    <dynamics damping="0.5" friction="0.05"/>
  </joint>

  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
  <joint name="${P}joint8" type="prismatic">
    <origin xyz="0 0 0.13503" rpy="-1.5708 0 1.5708"/>
    <parent link="${P}Link6"/><child link="${P}Link8"/>
    <axis xyz="0 0 1"/>
    <limit lower="-0.035" upper="0" effort="60" velocity="0.5"/>
    <dynamics damping="0.5" friction="0.05"/>
  </joint>

  <joint name="${P}joint_tcp" type="fixed">
    <origin xyz="0 0 0.145" rpy="0 0 0"/>
    <parent link="${P}Link6"/><child link="${P}tcp"/>
  </joint>

  <xacro:if value="$(arg fijar_a_mundo)">
    <link name="world"/>
    <joint name="${P}anclaje_mundo" type="fixed">
      <parent link="world"/><child link="${P}base_link"/>
      <origin xyz="$(arg base_x) $(arg base_y) $(arg base_z)" rpy="0 0 $(arg base_yaw)"/>
    </joint>
  </xacro:if>

  <xacro:if value="$(arg usar_gazebo)">
    <xacro:include filename="$(find piper_celda_description)/urdf/piper_x.gazebo.xacro"/>
    <xacro:piper_gazebo prefix="$(arg prefix)" controllers_file="$(arg controllers_file)"/>
  </xacro:if>

</robot>

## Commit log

2026-08-27 Celda de digitalizacion con PiPER X: Gazebo Harmonic + MoveIt 2
    [J1_col.stl, J2_col.stl, J3_col.stl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]
2026-09-01 Pick completo
    [joint_limits.yaml, piper_controllers.yaml, piper_x.gazebo.xacro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]
2026-09-03 Rev. 3: rack de 90 ranuras sustituye al escurridor
    El escurridor_60 daba 8 mm de paso con el espesor de la laminilla en X del
    mundo. El rack da 6.8 mm con el espesor en Y, y eso invierte el agarre: por
    cantos ya no cabe (los tabiques dejan 2 mm) y hay que ir por las caras,
    metiendo el dedo entre vecinas.
    Mundo
    - Cuatro racks (rack_in_1, rack_in_2, rack_out_3, rack_out_4) en lugar de
    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
    [celda_piper.sdf, escurridor_60.stl, model.sdf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]
2026-09-03 Limpieza: rutas relativas y arbol sin directorios fantasma
    Rutas
    Los tres paquetes de src/ ya eran reubicables (get_package_share_directory,
    package://, model://). Las herramientas no: cinco lineas asumian que el
    proyecto vivia exactamente en ~/Omica/PiperCelda. Ahora la raiz se deriva
    de Path(__file__).resolve().parents[1], asi que el repo se puede clonar en
    cualquier ruta. Los mensajes de ayuda de 11 y 12 tambien citaban la ruta
    antigua.
    CMakeLists
    piper_celda_gazebo instalaba un config/ que no existia y
    piper_celda_description un launch/ que solo tenia .gitkeep. Los dos
    directorios se eliminan junto con su linea de install().
    Tambien
    - models/rack_laminillas_lleno/me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
